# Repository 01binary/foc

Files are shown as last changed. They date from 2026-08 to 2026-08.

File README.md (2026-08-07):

# Field-Oriented Control Drive

A board that controls BLDC motors in robot joints, based on [SimpleFOC Drive Shield](https://github.com/simplefoc/SimpleFOC-DriveShield).

|Feature|Description|
|-|-|
|Current|`20A` continuous, `30A` peak, `75A` max|
|Voltage|`30V` max|
|Encoders|[AS5047D](https://www.digikey.com/en/products/detail/ams-osram-usa-inc/as5047d-atst-tssop14-lf-t-rdp/4896031) (Onboard), [ASKIM2](https://www.rls.si/eng/aksim-2-off-axis-rotary-absolute-encoder) (External)|
|Driver|[DRV8320HRTVT](https://www.digikey.com/en/products/detail/texas-instruments/drv8320hrtvt/7426985) Triple Half-Bridge Gate Driver|
|Communication|[MCP2562FDT-E/MF](https://www.mouser.com/en/ProductDetail/Microchip-Technology/MCP2562FDT-E-MF) CAN-FD Transceiver|
|Power|`12V` from [XT60PW-F](https://www.aliexpress.us/item/3256808202387933.html)|

## Microcontroller

This board uses [STM32G474RBT3](https://www.digikey.com/en/products/detail/stmicroelectronics/STM32G474RBT3/10326726) MCU.

|Specification|Value|
|-|-|
|Power|`3.3V`|
|Memory|`512 KB` Flash, `96 KB` SRAM|
|ADC|5x `12-bit` ADC, up to `16-bit`|
|DAC|7x `12-bit` DAC|
|Timers|17x|
|Interfaces|`CAN-FD`, `I2C`, `UART`, `SPI`, `USB 2.0`|
|Capabilities|`CORDIC` for Trigonometric Function, `FMAC` Filter Mathematical Accelerator|

## Motor Driver

The [DRV8320HRTVT](https://www.digikey.com/en/products/detail/texas-instruments/drv8320hrtvt/7426985) Triple Half-Bridge Gate Driver with Hardare interface is used to drive three N-channel power MOFSETs.

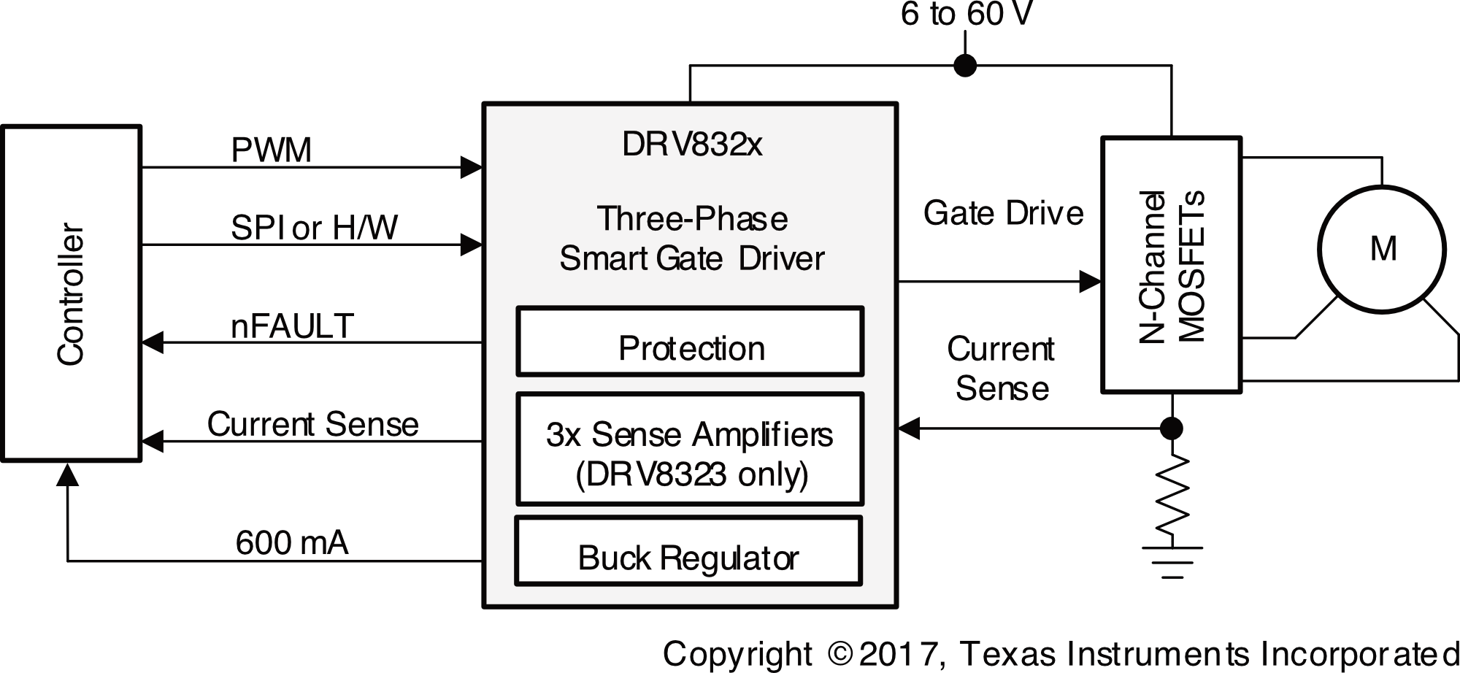
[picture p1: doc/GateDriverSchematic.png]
Gate Driver


+ `1.8V`, `3.3V`, and `5V` Logic Inputs
+ Adjustable Slew Rate Control
+ Up to 100% PWM Duty Cycle
+ High-Side Charge Pump
+ Low-SIde Linear Regulator
+ `4V` to `6 V` Operating Voltage
+ `0.8mA` to `600mA` Output Capability

## MOSFETs

The [BSZ0904NSI](https://www.lcsc.com/datasheet/C51908785.pdf) `30V` `60A` N-channel power MOSFETs are used to drive a single 3-phase brushless DC motor.

## Current Sense

Current is sensed by using the [3-Shunt, Amplified Current Sensing](https://wiki.st.com/stm32mcu/wiki/STM32MotorControl:Motor_Control_Boards_Description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) scheme from STM32 user guide:

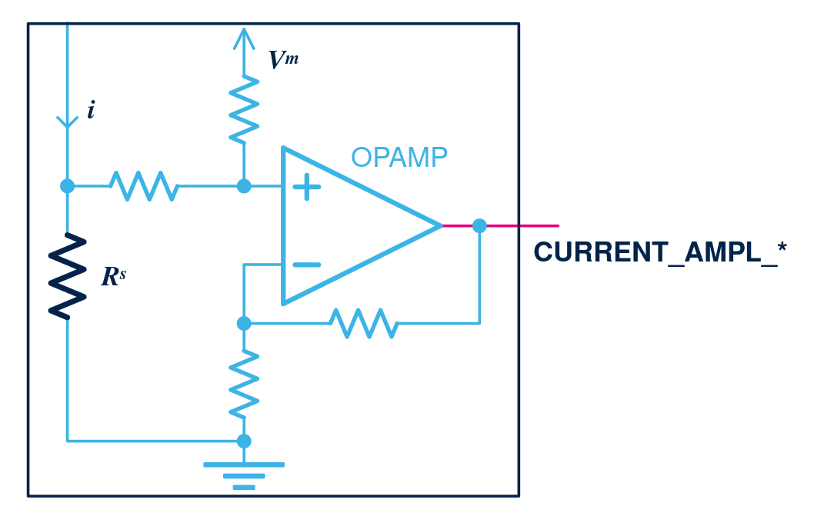
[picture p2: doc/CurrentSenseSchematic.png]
Current Sense


|Component|Description|
|-|-|
|[HoJLR2512-3W-2mR-1%](https://jlcpcb.com/partdetail/Milliohm-HoJLR2512_3W_2mR_1/C2903471)|`2mΩ` `3W` Current Sense Resistor SMD ±1% 2512 Current Sense Resistors / Shunt Resistors|
|[INA240A1PWR](https://jlcpcb.com/partdetail/TexasInstruments-INA240A1PWR/C93965)|Op-Amps|

## Encoders

The board supports dual encoders:

+ AS5047D on the motor (before gearbox)
+ ASKIM-2 mounted on the drive (after gearbox)

### Onboard Encoder

The onboard AS5047D high-resolution encoder with `SPI` interface is mounted on the board:

|Pin|Signal|
|-|-|
|1|`CS`|
|2|`CLK`|
|3|`MISO`|
|4|`MOSI`|
|11|`5V`|

### External Encoder

The external absolute AKSIM-2 encoder with `SPI` interface uses a 10-pin FCI connector:

|Pin|Signal|
|-|-|
|1|`5V`|
|2|`GND`|
|3|External Temperature Sensor Pin 1 (Pass-Thru)|
|4|External Temperature Sensor Pin 2 (Pass-Thru)|
|5|`SCK`|
|6|`CS`|
|7|`MISO`|
|8|`MOSI`|

## Pin Mapping

|Pin|Net|
|-|-|
|`VBAT`|`+3.3V`|
|`PC13`|Status LED|
|`OSC32_IN`|`32.768kHz` Crystal Oscillator In|
|`OSC32_OUT`|`32.768kHz` Crystal Oscillator Out|
|`OSC_IN`|`8MHz` Crystal Oscillator In|
|`OSC_OUT`|`8Mhz` Crystal Oscillator Out|
|`RESET`|ARM JTAG Programmer Reset Pin|

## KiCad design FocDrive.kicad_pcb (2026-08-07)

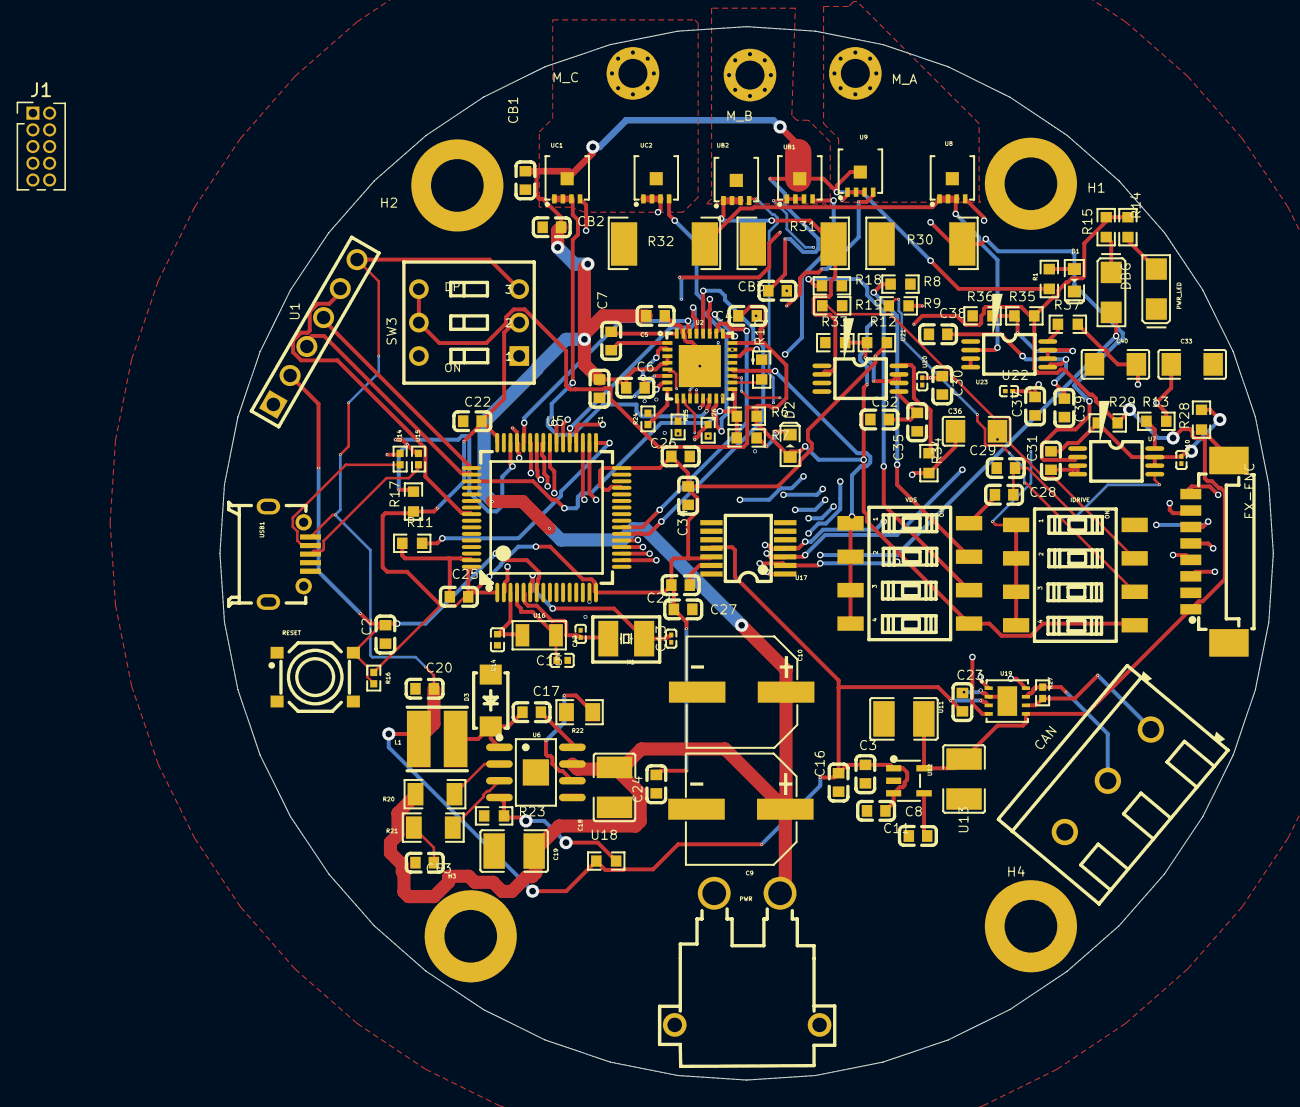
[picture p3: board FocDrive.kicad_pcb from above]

Board: 4 copper layers, 80.0 x 80.0 mm, 125 parts (0 on the bottom side), 85 nets.

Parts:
C1, C5: C0603B104K160NT; C0603
C2, C3, C4, C6, C8, C21, C30, C31, C37: 1uF; C0603
C7: 47nF; C0603
C9, C10: 220uF; CAP-SMD_BD8.0-L8.3-W8.3-LS9.5-FD
C11: 22nF; C0603
C12, C13: 20pF; C0201
C14, C15: 18pF; C0402
C16, C17, C22, C23, C24, C25, C26, C27, C28, C29, C32, C35, C38, C39: 100nF; C0603
C18, C19: 10uF; C1210
C20: 47uF; C0603
C33, C36, C40: 2.2nF; C1206
C34: 10nF; C0603
CAN: WJ500V-5.08; CONN-TH_3P-P5.00_WJ500V-5.08-3P
CB1, CB2, CB3: C0603B104K160NT; C0603
CF3: 1nF; C0603
D1, D2: LED-0603_R; LED0603_RED
D3: SS14; SMA_L4.2-W2.6-LS5.0-RD_1
DBG: LC150LGCT; LED1206-RD
EX-ENC: 10114830-11108LF; CONN-SMD_8P-P1.25_AMPHENOL_10114830-11108LF
H1, H2, H3, H4: HOLEHOLE COPY; HOLEHOLE
IDRIVE: 2.54-4P TPGT; SW-SMD_8P-L10.2-W6.2-P2.54-LS9.4
J1: Conn_ARM_JTAG_SWD_10; PinHeader_2x05_P1.27mm_Vertical
L1: 2.2UH,20%; IND-SMD_L4.0-W4.0_C9900022260
M_A: M2 PLATED HOLE WITH MINI HOLES
M_B: M2 PLATED HOLE WITH MINI HOLES
M_C: M2 PLATED HOLE WITH MINI HOLES
PWR: XT30PW-M; CONN-TH_XT30PW-M
PWR_LED: LC150LGCT; LED1206-RD
R1, R6, R7: 4.7k; R0603
R8, R19: 75k; R0603
R9, R18: 18k; R0603
R10: 47k; R0603
R11, R17: 4.7kΩ; R0603
R12, R28, R29, R33, R35, R36: 10kΩ; R0603
R13, R34, R37: 100Ω; R0603
R14, R15: 510Ω; R0603
R16: 10kΩ; R0402
R20, R21: 100kΩ; R1206
R22: 250kΩ; R0805
R23: 22kΩ; R0603
R24, R25, R26: 0Ω; R0402
R27: 120Ω; R0402
R30, R31, R32: 2mΩ; RES-SMD_L6.4-W3.2-R2512
RESET: HX 5.2X5.2X1.5H SWITCH TACTILE; SW-SMD_4P-L5.2-W5.2-P3.7-LS6.4-1
SW3: KH-BM2.54-3P; SW-TH_KH-BM2.54-3P
U1: HC-PM254-8.5H-1X6PZ; HDR-TH_HC-PM254-8.5H-1X6PZ
U2: DRV8320HRTVT; WQFN-32_L5.0-W5.0-P0.50-TL-EP
U5: STM32G474RBT3; LQFP-64_L10.0-W10.0-P0.50-LS12.0-BL
U6: MP1584EN-LF-Z; SOIC-8_L5.0-W4.0-P1.27-LS6.0-BL-EP2.0
U7, U21, U23: INA240A1PWR; TSSOP-8_L4.4-W3.0-P0.65-LS6.4-BL
U8, U9: BSZ0901NSATMA1; DFN-8_L3.3-W3.3-P0.65-BL-2
U10, U20, U22: 100nF; C0201
U11, U13: 10uF; C1210
U12: RT9193-33GB; SOT-23-5_L3.0-W1.7-P0.95-LS2.8-BL
U14, U15: 20Ω; R0402
U16: 32.768kHz; CRYSTAL-SMD_L3.2-W1.5-1
U17: AS5047D-ATSM; TSSOP-14_L5.0-W4.4-P0.65-LS6.4-BL
U18: 118kΩ; R0603
U19: MCP2562FDT-E/MF; DFN-8_L3.0-W3.0-P0.65-BL-EP
UB1, UB2: BSZ0901NSATMA1; DFN-8_L3.3-W3.3-P0.65-BL-2
UC1, UC2: BSZ0901NSATMA1; DFN-8_L3.3-W3.3-P0.65-BL-2
USB1: HX USB-MICR XNJ ZB; MICRO-USB-SMD_HX-USB-MICRO-XNJ-JB
VDS: 2.54-4P TPGT; SW-SMD_8P-L10.2-W6.2-P2.54-LS9.4
X1: 8MHz; CRYSTAL-SMD_L3.2-W2.5_3225-8MHZ

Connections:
$1N2: D1.1, R1.1
$1N29: C7.1, U2.32
$1N30: C7.2, U2.1
$1N32: C6.2, U2.2
$1N71: PWR_LED.2, R14.1
$1N76: DBG.1, R15.1
$1N85: C11.2, U12.4
$1N91: U14.1, USB1.2
$1N92: U15.1, USB1.3
$1N109: R18.1, VDS.6
$1N110: R8.1, VDS.7
$1N111: IDRIVE.6, R9.1
$1N112: IDRIVE.7, R19.1
$1N122: R20.2, U6.2
$1N125: C17.2, U6.8
$1N126: C17.1, D3.1, L1.2, U6.1
$1N127: R23.2, U6.4, U18.2
$1N128: R21.2, U6.3
$1N130: CF3.1, R21.1
$1N134: R22.2, U6.6
$1N158: CAN.3, R27.2, U19.6
$1N159: CAN.2, R27.1, U19.7
$1N209: C28.2, C29.2, U7.5
$1N211: C31.2, R28.2, R29.1, U7.6, U7.7, U10.2
$1N213: R13.1, U7.8
$1N225: C30.2, R12.1, R33.2, U20.2, U21.6, U21.7
$1N230: R34.1, U21.8
$1N233: C32.2, C35.2, U21.5
$1N236: C37.2, R35.1, R36.2, U22.2, U23.6, U23.7
$1N241: R37.1, U23.8
$1N244: C38.2, C39.2, U23.5
$1N3452: D2.2, R7.2
+3.3V: C21.2, C22.2, C24.2, C25.2, C26.2, C27.2, C34.2, EX-ENC.1, J1.1 (VTref), R12.2, R14.2, R15.2, R16.2, R17.1, R29.2, R35.2, SW3.2, U5.1, U5.16, U5.29, U5.32, U5.48, U5.64, U11.2, U12.5, U13.2, U17.12, U19.5
+5V: C3.2, C8.2, C16.2, C20.2, C23.2, L1.1, SW3.3, U1.6, U12.1, U12.3, U17.11, U18.1, U19.3, USB1.1
CS: U5.18, U17.1
CS2: EX-ENC.6, U5.42
DVDD: C4.2, D2.1, IDRIVE.5, R6.2, R9.2, SW3.4, SW3.5, U2.24, VDS.5
ENABLE: R11.2, U2.22, U5.33
GHA: U2.5, U9.4
GHB: U2.12, UB1.4
GHC: U2.13, UC1.4
GLA: U2.7, U8.4
GLB: U2.10, UB2.4
GLC: U2.15, UC2.4
GND: C1.1, C2.1, C3.1, C4.1, C5.1, C8.1, C9.2, C10.2, C11.1, C12.1, C13.1, C14.1, C15.1, C16.1, C18.1, C19.1, C20.1, C21.1, C22.1, C23.1, C24.1, C25.1, C26.1, C27.1, C28.1, C29.1, C30.1, C31.1, C32.1, C33.1, C34.1, C35.1, C36.1, C37.1, C38.1, C39.1, C40.1, CAN.1, CB1.2, CB2.1, CB3.2, CF3.2, D1.2, D3.2, EX-ENC.2, EX-ENC.9, EX-ENC.10, IDRIVE.8, J1.3 (GND), J1.5 (GND), J1.9 (GNDDetect), PWR.1, PWR_LED.1, R8.2, R10.2, R11.1, R18.2, R19.2, R22.1, R23.1, R24.2, R25.2, R26.2, R28.1, R30.1, R31.1, R32.1, R33.1, R36.1, RESET.4, U1.1, U2.23, U2.31, U2.33, U5.15, U5.27, U5.31, U5.47, U5.63, U6.5, U6.9, U7.3, U7.4, U10.1, U11.1, U12.2, U13.1, U17.5, U17.13, U19.2, U19.9, U20.1, U21.3, U21.4, U22.1, U23.3, U23.4, USB1.4, USB1.5, USB1.6, USB1.7, USB1.8, USB1.9, VDS.8
IDRIVE: IDRIVE.1, IDRIVE.2, IDRIVE.3, IDRIVE.4, U2.19
IN1+: R30.2, U7.2, UC2.1, UC2.2, UC2.3
IN2+: R31.2, U21.2, UB2.1, UB2.2, UB2.3
IN3+: R32.2, U8.1, U8.2, U8.3, U23.2
INHA: U2.25, U5.39
INHB: U2.27, U5.38
INHC: U2.29, U5.37
INLA: U2.26, U5.23
INLB: U2.28, U5.22
INLC: U2.30, U5.44
MISO: EX-ENC.7, U5.20, U17.3
MODE: R10.1, U2.18
MOSI: EX-ENC.8, U5.21, U17.4
NFLT: R6.1, R7.1, U2.17, U5.51
OSC1: C12.2, U5.5, X1.2
OSC2: C13.2, U5.6, X1.1
OSC3: C14.2, U5.3, U16.2
OSC4: C15.2, U5.4, U16.1
PA11: U5.45, U14.2, U19.4
PA12: R17.2, U5.46, U15.2, U19.1
PC13: DBG.2, U5.2
PHASE1: C33.2, R13.2, U5.36
PHASE2: C36.2, R34.2, U5.35
PHASE3: C40.2, R37.2, U5.34
RESET: C2.2, R16.1, RESET.2, U1.2, U5.7
SCK: EX-ENC.5, U5.19, U17.2
SHA: M_A.1, U2.6, U8.5, U9.1, U9.2, U9.3
SHB: M_B.1, U2.11, UB1.1, UB1.2, UB1.3, UB2.5
SHC: M_C.1, U2.14, UC1.1, UC1.2, UC1.3, UC2.5
SLA: R24.1, U2.8
SLB: R25.1, U2.9
SLC: R26.1, U2.16
STBY: U5.40, U19.8
SWCLK: U1.3, U5.50
SWDIO: U1.4, U5.49
SWO: U1.5, U5.56
TEMP1: EX-ENC.3, U5.43
TEMP2: EX-ENC.4, U5.41
VCC: C1.2, C5.2, C6.1, C9.1, C10.1, C18.2, C19.2, CB1.1, CB2.2, CB3.1, PWR.2, R1.2, R20.1, U2.3, U2.4, U6.7, U9.5, UB1.5, UC1.5
VDS: U2.20, VDS.1, VDS.2, VDS.3, VDS.4

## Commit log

2026-08-05 Cleanup first pass
    [FocDrive.kicad_pcb, FocDrive.kicad_sch, SimpleFOC_DrivePRO.kicad_pcb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]
2026-08-06 Second cleanup pass
    [FocDrive.kicad_sch]
2026-08-06 Power voltage
2026-08-07 More minor edits
    [FocDrive.kicad_pcb]
